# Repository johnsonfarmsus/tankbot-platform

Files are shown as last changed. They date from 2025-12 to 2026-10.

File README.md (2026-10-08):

# TankBot

**A robot platform that scales with what you plug into it, and to whatever size you build it.**

Start with an ESP32, a motor driver and a chassis, and you have a robot you can drive from a browser.
Add a bumper and distance sensors, and it protects itself. Put a phone on it, and the phone becomes its
brain. Add a lidar, and it maps your house, keeps the map straight, drives itself to wherever you tap,
and explores rooms it hasn't seen yet, all on hardware you probably already own.

<table align="center"><tr>
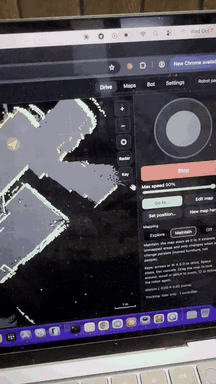
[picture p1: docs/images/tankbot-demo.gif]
TankBot in action
<td align="center"><br><em>In action</em></td>
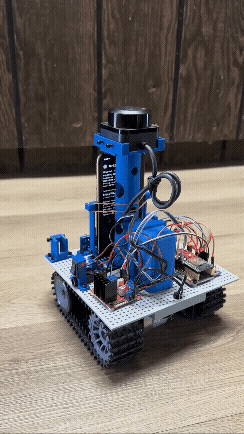
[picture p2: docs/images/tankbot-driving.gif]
TankBot driving
<td align="center"><br><em>Driving</em></td>
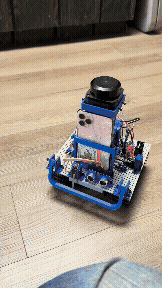
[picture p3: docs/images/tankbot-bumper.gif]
The bumper reflex
<td align="center"><br><em>Bumper reflex</em></td>
</tr></table>

TankBot grew out of the original [TankBot ESP32](https://github.com/johnsonfarmsus/tank-bot-esp32), a
web-controlled tracked robot. This project turns it into a platform: the same software for any robot
you build on it.

## One platform, any robot, any size

Nothing in TankBot is written for one particular robot. Each robot is **described** in its *bot
profile*: how big it is, how it drives, and where every sensor sits and how high. Everything else works
from that description:

- **Planning and safety use the robot's real footprint.** Routes keep its body (plus the clearance you
  choose) away from walls; the "is it clear ahead?" check uses its actual front edge and width.
- **Sensors are placed, not hard-coded.** Any number of bumpers, ultrasonic and ToF sensors, in any
  direction, each with a role (obstacle, cliff, bump). The robot reacts in the direction each one faces.
  The lidar and camera positions turn their readings into the robot's frame.
- **Driving adapts to the machine:** minimum and cruise power, steering trim, stop and pass distances,
  turn behaviour.
- **Maps are in metres, not robot sizes:** 5 cm cells, room for a whole house (up to 40 m across).
- **Brains are interchangeable.** Any iPhone with ARKit can be the brain (tested: SE 2nd gen, 11 Pro,
  12 Pro; a LiDAR iPhone adds a depth camera), mounted on the robot or held in hand. The robot itself keeps its settings, sensors and a
  compact copy of its map, so a new phone picks everything up when it connects.

| | TankBot (today) | Wheelchair base (next) | Yours |
|---|---|---|---|
| Size | 18.5 x 17 cm platform | wheelchair-sized | describe it in the profile |
| Drive | tank tracks | two powered wheels + casters | tank or two-wheel (mecanum planned) |
| Brain | iPhone on a 3D-printed tower | a phone on the chassis | any ARKit iPhone, mounted or in hand |
| Sensors | lidar, front bumper, ultrasonic | lidar, bumpers, rangers all round | whatever you attach, wherever it sits |
| Software changes | | none planned: a new profile | none: a new profile |

The **capability tiers** below grow with the hardware: every part you add unlocks more, and the app
shows what the next part would unlock.

## Build one

### Parts list

**Electronics**

| Part | Qty | Used for | Notes |
|---|---|---|---|
| **ESP32 DevKit**, 38-pin (CP2102, USB-C) | 1 | the robot's controller | |
| **ESP32 38-pin expansion board** ("ESP32S 38P V4" style) | 1 | mounts the ESP32; power and wiring | DC input 6.5-16 V, onboard 5 V and 3.3 V, an S/V/G header for every pin (a jumper sets V to 3.3 V or 5 V). Also powers the lidar (5 V) |
| **L298N** H-bridge motor driver | 1 | drives both tracks | remove the ENA / ENB jumpers so the ESP32 controls speed |
| **TP101 tracked chassis** with 2x **33GB-520-18.7F** DC motors | 1 | the robot base | |
| **12 V Li-ion battery pack**, 3S (11.1 V, 9-12.6 V), ~5600 mAh, 5 A | 1 | power | we use a Mspalocell XZ01 kit: it comes with a 12.6 V 1 A charger, bare leads, a DC barrel connector, lever connectors and barrel-to-screw-terminal adapters, which cover all the power wiring |
| **Mini rocker switch**, SPST on/off, 2-pin pre-wired (KCD1-101 type) | 1 | main power switch | fits the printed charger clamp with switch; sold in packs (e.g. AKVIBG 10-pack) |
| **Dupont jumper wires** (female-female and male-female) | a pack | every signal and sensor connection | the expansion board's S/V/G headers take standard Dupont plugs |

**Sensors**

| Part | Qty | Used for | Notes |
|---|---|---|---|
| **Slamtec RPLidar C1** | 1 | mapping, position, navigation | on the printed lidar tower; 5 V from the expansion board |
| **HC-SR04P** ultrasonic (wide-voltage 3-5.5 V) | 1 | low obstacles ahead | powered from 3.3 V so its echo is safe for the ESP32 |
| **V-153-1C25** micro switch | 1 | front bumper | behind the printed bumper bar |
| *Optional:* **TOFSense-F2 Mini** ToF sensor | 1 | cliff (drop-off) sensor, aimed at the floor | JST GH 1.25 mm connector |

**Brain**

| Part | Qty | Used for | Notes |
|---|---|---|---|
| **An iPhone with ARKit** | 1 | the brain | tested: SE (2nd gen), 11 Pro, 12 Pro; a LiDAR iPhone adds the depth camera. It runs on its own battery |

**Hardware**

| Part | Qty | Used for | Notes |
|---|---|---|---|
| **M3 x 6 mm socket head cap screws** | a pack (a full build uses under 50) | everything | the only fastener: every printed part, board and module mounts with these |
| [**3D-printed parts**](https://www.printables.com/model/1869360-tankbot) | 1 set | tower, mounts, clamps, bumper | on Printables |

**Recommended upgrade:** a **12 V to 5 V buck converter** (2 A or more) for the 5 V rail. The expansion
board's onboard 5 V is a small linear regulator that runs hot feeding the lidar and the ESP32 from a 12 V
battery; a buck converter runs cool. It is also what you would need to charge the phone from the robot,
though the battery above is better kept for driving.

### Build steps

1. **Print the parts** from [Printables](https://www.printables.com/model/1869360-tankbot) (base plate,
   lidar tower and base, phone base and clamp, bumper and switch mount, two-part ultrasonic mount, battery
   and charger clamps, a 2-wire connector, wire management, spacers). If Printables is ever unavailable,
   a backup zip of the model files is in [`hardware/`](hardware).
2. **Assemble** the chassis and mount the printed parts, the boards and the sensors, all with M3 x 6 mm
   screws. The printed spacers sit between each board and the base to lift it off.
3. **Wire it** following [docs/wiring.md](docs/wiring.md): battery through the rocker switch to the
   expansion board and the L298N, then the motors, lidar, ultrasonic and bumper with Dupont wires.
4. **Flash and set it up** following *Setting up a robot* below.

<p align="center">
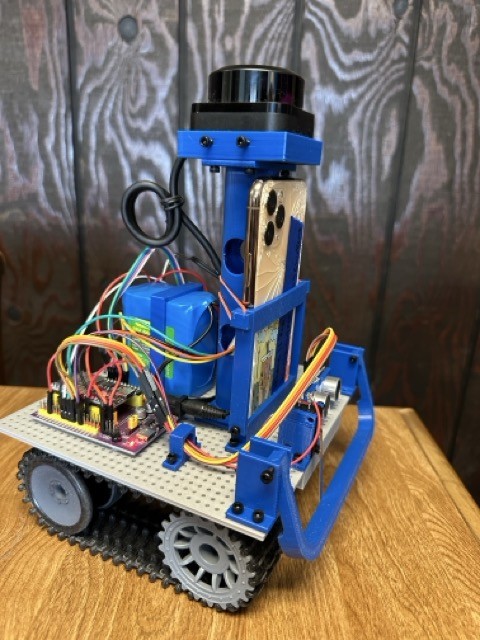
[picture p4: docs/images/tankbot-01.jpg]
TankBot photo 1

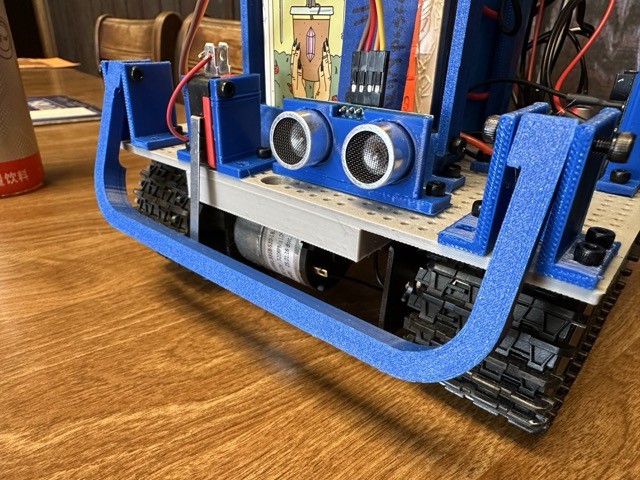
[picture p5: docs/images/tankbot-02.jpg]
TankBot photo 2

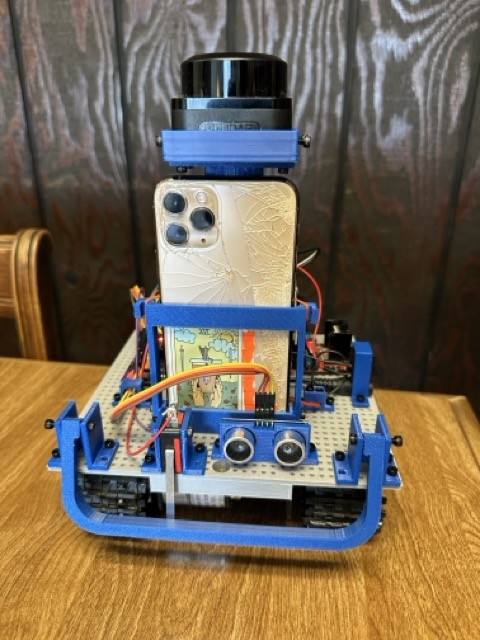
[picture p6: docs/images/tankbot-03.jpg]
TankBot photo 3

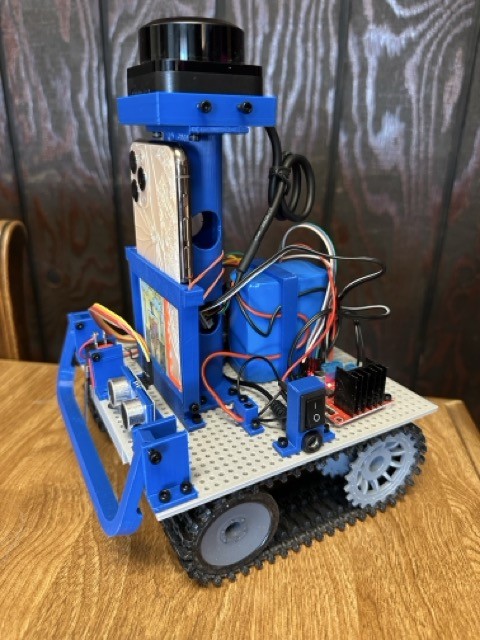
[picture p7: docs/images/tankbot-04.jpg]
TankBot photo 4

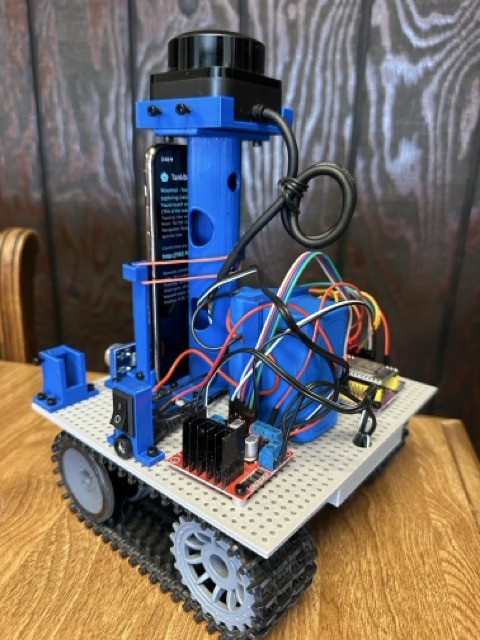
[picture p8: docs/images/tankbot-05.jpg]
TankBot photo 5

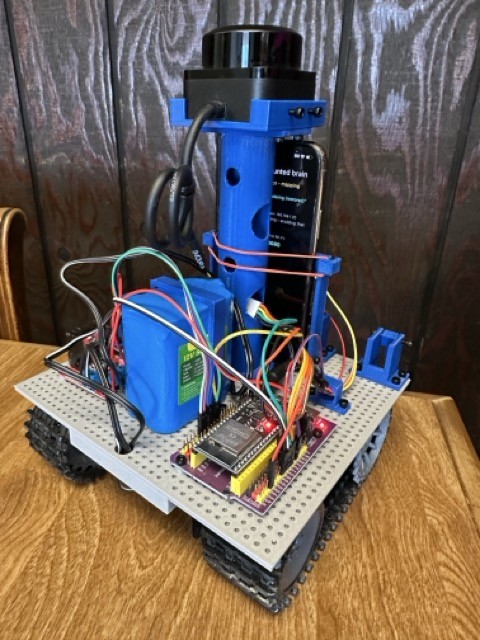
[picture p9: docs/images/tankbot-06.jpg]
TankBot photo 6

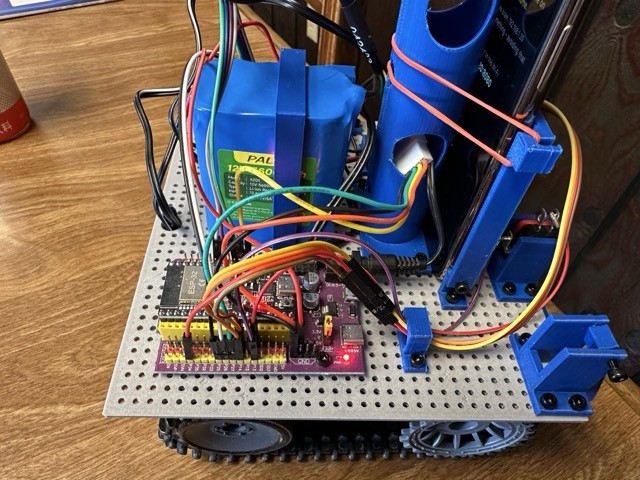
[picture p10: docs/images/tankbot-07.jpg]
TankBot photo 7

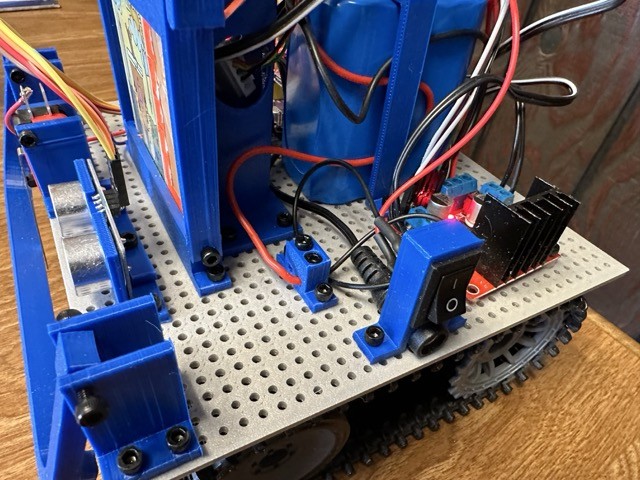
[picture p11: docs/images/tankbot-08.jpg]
TankBot photo 8

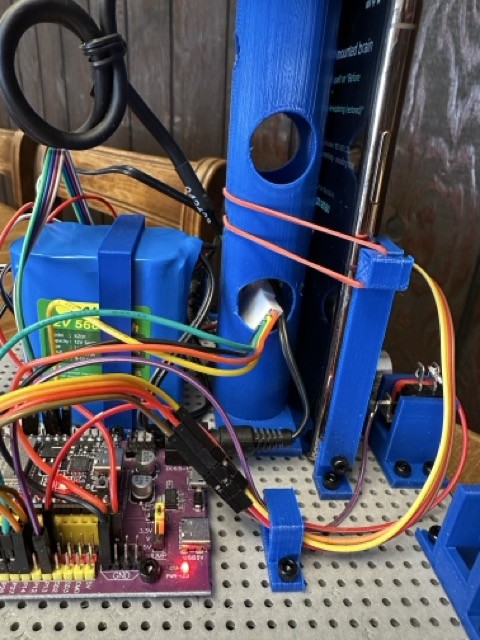
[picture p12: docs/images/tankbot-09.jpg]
TankBot photo 9

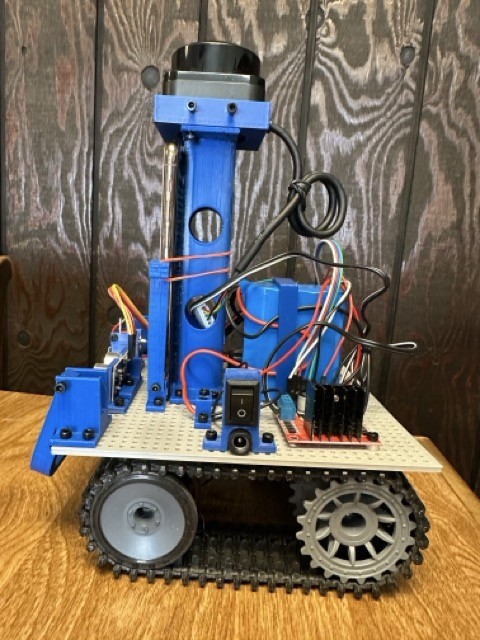
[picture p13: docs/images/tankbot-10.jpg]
TankBot photo 10

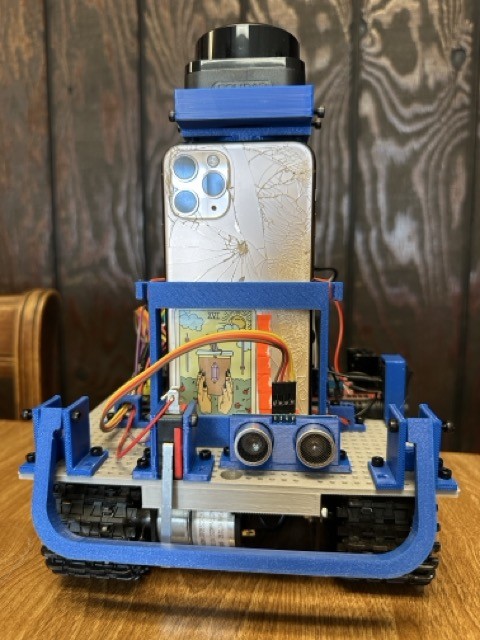
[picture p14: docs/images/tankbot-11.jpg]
TankBot photo 11

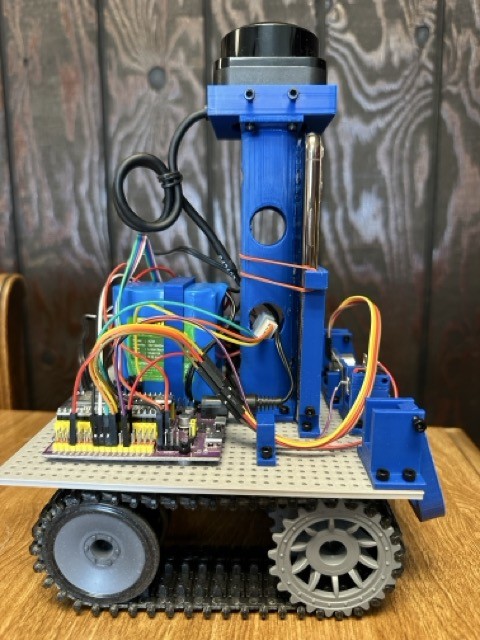
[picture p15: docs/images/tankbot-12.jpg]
TankBot photo 12

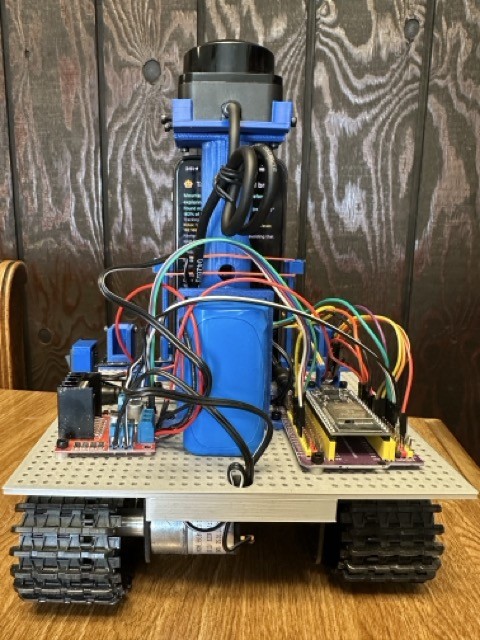
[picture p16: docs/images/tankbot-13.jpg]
TankBot photo 13

</p>

TankBot grew out of the original [TankBot ESP32](https://github.com/johnsonfarmsus/tank-bot-esp32)
(a browser-driven tracked robot, with its own [Printables parts](https://www.printables.com/model/1516204-tank-bot-esp32)).
Building something bigger? The same steps apply: a motor driver that suits your motors, the sensors you
want where you want them, and a profile that describes it.

## How it fits together

```
 Robot (ESP32)                         Brain (phone/tablet running the app)         Controllers
 motors + watchdog                 --->  tracking: camera + lidar scan matching  <---  web browser
 reflexes: bumper / cliff / range        map: keyframes, loop closing, edits           (any laptop)
 lidar bridge                            guardian: is forward clear, and why?    <---  the app in
 sensor feed + capability announce       navigator: plan a route, drive it             Controller role
 own web page (drive + setup)            control server (web pages + live data)
```

Every part reads the robot's geometry from a **bot profile** (size, drive type, where each sensor
sits). Nothing about a specific robot is hard-coded.

## Capability tiers

| Tier | Hardware | You get |
|---|---|---|
| Drive | ESP32 + motor driver + chassis | manual driving from the ESP32's own web page |
| Reflexes | + bumpers, ToF, ultrasonic | bump stop and back-off, cliff stop, close-obstacle stop, on the ESP32 itself |
| Brain | + a phone or tablet running the app | full controller, position tracking (mounted), the robot's status face |
| Mapping | + RPLidar | maps, remembering places, relocalisation, tap-to-go |
| 3D awareness | + a phone with a depth camera (LiDAR iPhone) | low obstacles and drop-offs the lidar can't see |

The controller's Settings page shows the current tier and what would unlock the next.

## Repository layout

| Folder | Contents |
|---|---|
| `firmware/tankbot/` | ESP32 firmware v3: sensor table, directional reflexes, lidar bridge, sensor feed, web page, OTA |
| `firmware/motion/` | the original TankBot firmware, kept for reference |
| `app/tankbot_brain/` | the **TankBot** app (Flutter): Mounted brain / Brain in hand / Controller roles |
| `docs/` | [user guide](docs/user-guide.md), [wiring](docs/wiring.md), [protocol](docs/protocol.md), [bot profile](docs/bot-profile.md), [app architecture](docs/app-architecture.md), [diagnostics](docs/diagnostics.md), [roadmap](docs/ROADMAP.md), [changelog](CHANGELOG.md) |
| `tools/` | desktop helpers: log analysis, brain commands, controller checks ([tools/README](tools/README.md)) |
| `hardware/` | a backup zip of the 3D-printed parts (STL + Fusion 360); get the parts from [Printables](https://www.printables.com/model/1869360-tankbot) |

## Setting up a robot

1. **Wire it** following [docs/wiring.md](docs/wiring.md). Start with the motor driver; add sensors
   any time.
2. **Flash the firmware.** Copy `firmware/tankbot/src/secrets.example.h` to `secrets.h`, enter your
   2.4 GHz Wi-Fi, an OTA password and a hotspot password, then `cd firmware/tankbot && pio run -t upload` over USB once.
   From then on `pio run -e ota -t upload` updates it over Wi-Fi.
3. **Drive it.** Open `http://tankbot.local/` on any device on your Wi-Fi (buttons, joystick, or the
   arrow keys / W A S D on a computer) (away from home the robot
   broadcasts its own `TankBot` network instead). Speed levels and steering trim live here too.
4. **Tell it what's attached.** Once a brain is running (below), the **Bot** page describes the whole
   robot: its size and drive type, and each sensor's role, facing and position; its **Wiring** view
   sets and checks the pins (defaults match docs/wiring.md) with test buttons. Save sends it to the
   robot, which keeps it. `http://tankbot.local/setup` covers Wi-Fi, name and pins. A ToF aimed
   at the floor? Press Calibrate on its card once.

## Adding a brain

1. Install the **TankBot** app on a phone (iOS today; Android when ARCore support lands). Each time it
   opens it asks what the device is doing:
   - **Mounted brain**: the phone rides on the robot; camera tracking, mount detection, status face.
   - **Brain in hand**: same brain off the robot, tracking with the lidar alone.
   - **Controller**: a remote for a brain on the network.
2. Open **`http://tankbot.local/brain`** in any browser on the same Wi-Fi: the robot sends you to
   wherever the brain is (bookmark it). The robot's own page (`tankbot.local`) also shows an
   "Open full controls" button whenever a brain is running. The app's Controller role works too.
3. Controller pages: **Drive** (map you can drag, zoom and pinch, follow-the-robot, a colour key,
   joystick, arrow keys, radar view, Go to... anywhere on the map, status cards with actions), **Maps**
   (save, load, edit, no-go lines, map quality), **Bot** (the profile: platform size, sensor
   positions and heights), **Settings** (trim, power levels, obstacle stop and pass distances,
   what the robot and the phone can do).

### Which phone, and mounting it

Any iPhone with ARKit works as a brain. A LiDAR iPhone (12 Pro and later Pros) adds the depth camera
(low obstacles, drop-offs); without one (e.g. iPhone SE) the brain runs one tier down and falls back to
lidar-only tracking when the camera drifts (dim rooms, plain walls).

Mount it upright or on its side (set "Brain phone mounted" on the Bot page; the screen locks to it)
with the back camera facing forward. Enter the camera's position and height in the Bot page.
In Robot mode the brain waits until the phone has sat still in its cradle for 3 s before mapping, so
handling the phone never smears a map. If the phone gets knocked, mapping pauses until it settles.

## Mapping and driving

See the [user guide](docs/user-guide.md) for every page, button and map symbol.

- **Mapping modes:** Explore (build the map deliberately), Maintain (default: grows into new areas and
  only changes for persistent changes), Off. Bumps and drop-offs are temporary unless they recur.
- **Go to...:** click anywhere on the map. It plans around walls, no-go lines and live obstacles,
  backs away and re-plans when blocked or stalled, and stands still when unsure where it is.
- **Explore on its own** (Explore mode): drives to unexplored edges room by room and comes home.
- **Set position** when it's lost; **restore points** undo bad mapping (Maps page).
- Map straightening keeps long maps square (wall alignment, loop closing, good GPS outdoors).
- Safety is layered: ESP32 watchdog -> on-board reflexes -> the brain's guardian -> the controller's
  watchdog. Autonomous driving always runs its own obstacle checks.
- Trip, position-event and sensor logs record what happened; see [diagnostics](docs/diagnostics.md).

## Developing

- Firmware: PlatformIO. `pio run -e esp32dev` builds; `pio run -e ota -t upload` deploys over Wi-Fi.
- App: Flutter 3.32+. `flutter test` runs the mapping, matching, planning, guardian, pose graph and
  exploration tests (must pass before every install);
  `flutter build ios` / Xcode for the phone.
- The wire protocols are in [docs/protocol.md](docs/protocol.md); `tools/lidar_client.py` is a
  minimal reference client.

## Security and privacy

For a trusted home network: the robot's and brain's controls have no login, so never expose them to
the internet. Everything the app collects stays on your devices. Details, and the pre-commit secret
check (`git config core.hooksPath .githooks`), in [SECURITY.md](SECURITY.md).

## License

GNU AGPL 3.0 (inherited from tank-bot-esp32).

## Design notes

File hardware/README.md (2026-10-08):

# TankBot 3D-printed parts

**Get the parts from Printables:** [TankBot on Printables](https://www.printables.com/model/1869360-tankbot).
That is the home of the TankBot parts: print settings, photos, updated parts and new additions all land
there first. Downloading, liking and posting your makes there also supports the project.

[`tankbot-modelfiles.zip`](tankbot-modelfiles.zip) here is a ready-to-go backup pack of the parts as
of this release, in case Printables is ever unavailable: `.stl` files to print and `.f3d` Fusion 360
sources. It is not updated as often as Printables.

**In the pack:** base plate, lidar tower and lidar base, phone base and phone clamp, bumper and bumper
switch mount, two-part ultrasonic mount, battery clamp, charger clamp (with and without a switch),
2-wire connector, wire management, and spacers (they sit between an electronics board and the base,
with the screw passing through both, to lift the board off).

**One screw for everything:** every printed part, board and module mounts with **M3 x 6 mm socket head
cap screws**.

The base robot (chassis, motors, original mounting parts) comes from the original
[TankBot ESP32](https://github.com/johnsonfarmsus/tank-bot-esp32) project and its
[Printables parts](https://www.printables.com/model/1516204-tank-bot-esp32).

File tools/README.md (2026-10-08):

# Tools

Desktop helpers for developing and diagnosing the robot. Python 3; `analyze_sensor_log.py` and
`nopath_check.py` need numpy / matplotlib / Pillow (`~/tankbot-work/venv`). See `../docs/diagnostics.md`
for how to pull logs off the brain phone.

| Tool | What it does |
|---|---|
| `analyze_nav.py nav_*.csv` | breaks down a Go To / exploration trip: time by decision, motor bursts, interruptions, re-plans, turn reversals, timing and watchdog health |
| `analyze_sensor_log.py log_*.csv` | evaluates GPS and compass against the tracked path; writes a plot next to the log |
| `brain_send.py '{"type":"..."}'` | sends one controller message to the brain (default 192.168.1.99, or `BRAIN=host`) and prints pose, flash and exploration state |
| `nopath_check.py` | rebuilds what the planner sees from the live map and shows what boxes the robot in |
| `cdp_check.py URL [seconds] [js]` | loads the controller in headless Chrome, reports state and errors, optionally evaluates JS |
| `lidar_client.py` | minimal lidar client with a live plot (reference implementation of the protocol) |
| `wiring_check_test.js CONTROLLER_HTML` | runs the controller's wiring checker against 10 known scenarios (node) |
| `check_secrets.py` | the pre-commit secret check (enable with `git config core.hooksPath .githooks`) |
| `make_icon.py [artwork] [fill]` | regenerates the app icon at every iOS and Android size from one image |

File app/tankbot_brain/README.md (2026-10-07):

# TankBot app

The TankBot app (Flutter, iOS today): one app, three roles chosen at launch.

- **Mounted brain**: the phone rides on the robot (camera tracking, mapping, navigation, control server).
- **Brain in hand**: the same brain off the robot, tracking with the lidar alone.
- **Controller**: a remote for a brain on the network.

See the [project README](../../README.md), the [user guide](../../docs/user-guide.md) and the
[app architecture](../../docs/app-architecture.md). The Dart package is still named `tankbot_brain`
internally (folder, imports, bundle id `com.johnsonfarms.tankbotBrain`) so installed phones keep their data.

`flutter test` must pass before every install.

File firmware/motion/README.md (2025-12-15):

# TankBot - ESP32 Web-Controlled Tracked Robot

A web-controlled tank robot built with ESP32 and L298N motor driver, featuring a responsive web interface with speed control.

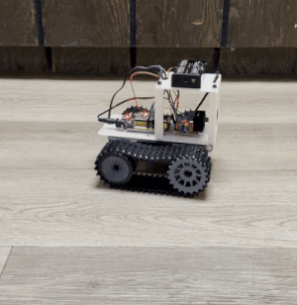
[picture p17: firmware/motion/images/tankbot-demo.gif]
TankBot in Action


## Hardware Components

- **Microcontroller**: ESP32 DevKit (38-pin, CP2102, USB-C)
- **Motor Driver**: L298N H-Bridge
- **Motors**: 2x 33GB-520-18.7F DC motors (included with chassis)
- **Chassis**: TP101 Tank-style chassis ([widely available](https://www.google.com/search?client=safari&rls=en&q=TP101+chassis&ie=UTF-8&oe=UTF-8))
- **Power**: 2x 18650 lithium batteries (7.4V nominal) (holder included with chassis)
- **Fasteners**: 12x M3x6 screws

### 3D Printed Parts

Custom mounting brackets and accessories are available on Printables: [TankBot ESP32 on Printables](https://www.printables.com/model/1516204-tank-bot-esp32)

## Wiring Diagram

### ESP32 to L298N Connections

| ESP32 Pin | L298N Pin | Function |
|---|---|---|
| P16 | IN1 | Left motor direction |
| P17 | IN2 | Left motor direction |
| P18 | IN3 | Right motor direction |
| P19 | IN4 | Right motor direction |
| P25 | ENA | Left motor speed (PWM) |
| P26 | ENB | Right motor speed (PWM) |
| GND | GND | Common ground |

### L298N Setup

1. **Remove the jumpers** from ENA and ENB pins on the L298N
2. Connect ENA to P25 and ENB to P26 as shown above
3. Connect your battery power to the L298N power input
4. Connect motors to OUT1/OUT2 (left) and OUT3/OUT4 (right)

### Power Connections

The TP101 chassis includes a dual 18650 battery holder with a power switch. Wire the power as follows:

1. **Battery to L298N**:
   - Connect battery holder red wire (+) to L298N 12V input
   - Connect battery holder black wire (-) to L298N GND

2. **L298N to ESP32**:
   - Connect ESP32 5V pin to L298N 5V input (this powers the L298N's logic circuitry)
   - Connect L298N GND to ESP32 GND (common ground)
   - The ESP32 is powered via USB during programming, or via a barrel plug connector tapped from the battery wires during operation

3. **Important Notes**:
   - The dual 18650 setup provides 7.4V nominal (8.4V fully charged)
   - The batteries power the L298N's motor outputs via the 12V input
   - The ESP32's 5V pin powers the L298N's logic circuitry
   - Always connect common ground between all components
   - During operation, power the ESP32 with a barrel plug connector from the battery wires

## Software Setup

### Prerequisites

- [PlatformIO](https://platformio.org/) installed in VSCode or via CLI
- USB cable to connect ESP32 to computer

### Installation

1. Open this project in PlatformIO:
   ```bash
   cd TankBot
   ```

2. Build the project:
   ```bash
   pio run
   ```

3. Upload to ESP32:
   ```bash
   pio run --target upload
   ```

4. Monitor serial output (optional):
   ```bash
   pio device monitor
   ```

### First Time Upload

If you encounter upload issues:
- Make sure the ESP32 is connected via USB
- Press and hold the BOOT button on ESP32 during upload if needed
- Check that the correct port is detected

## How to Use

1. **Power on the robot** - Connect battery and power up the ESP32

2. **Connect to WiFi**:
   - SSID: `TankBot`
   - Password: `tankbot2025`

3. **Open web interface**:
   - Open browser and go to: `http://192.168.4.1`

4. **Control the robot**:
   - **Button Mode** (default): Arrow buttons for Forward, Backward, Left, Right
     - Press and hold buttons to move, release to stop
     - Red STOP button for emergency stop
   - **Joystick Mode**: Click 🕹 icon (top-left) to toggle joystick control
     - Drag joystick to control direction and turning simultaneously
     - Forward/backward movement + left/right steering
     - Release joystick to stop
   - Adjust speed slider for 3 speed levels: Slow, Medium, Fast (works in both modes)

5. **Calibrate steering** (if robot drifts to one side):
   - Click the ⚙️ (gear) icon in the top-right corner to open Settings
   - Drive forward and observe which direction it drifts
   - Adjust the "Steering Trim" slider in the settings popup:
     - If drifting LEFT: Move slider to the RIGHT
     - If drifting RIGHT: Move slider to the LEFT
   - Fine-tune until robot drives straight
   - Close the settings popup (trim is automatically saved)

## Features

- **WiFi Access Point**: Robot creates its own WiFi network
- **Captive Portal**: Auto-popup control interface when connecting
- **Responsive Web UI**: Works on phones, tablets, and computers
- **Dual Control Modes**: Toggle between button controls and joystick
  - Button mode: Discrete directional controls (Forward, Backward, Left, Right)
  - Joystick mode: Analog control with simultaneous forward/back and turning
- **Speed Control**: 3 speed levels (Slow: 160, Medium: 220, Fast: 255)
- **Steering Trim**: Compensate for uneven track tension (-20 to +20 adjustment)
  - Trim value is saved to flash memory and persists between power cycles
  - Automatically loaded on startup
  - Works in both button and joystick modes
- **Real-time Feedback**: Status updates on web interface
- **Touch Support**: Works with touch screens for mobile control
- **mDNS Support**: Access via http://tank.local

## Control Mechanics

- **Forward/Backward**: Both motors run in same direction
- **Left**: Left motor backward, right motor forward (spin in place)
- **Right**: Left motor forward, right motor backward (spin in place)
- **Speed**: PWM control (0-255) on ENA/ENB pins

## Troubleshooting

### Robot doesn't move
- Check battery is charged and connected
- Verify all wiring connections
- Check that jumpers are removed from ENA/ENB
- Use serial monitor to see debug output

### Can't connect to WiFi
- ESP32 might still be booting (wait 10-15 seconds)
- Check password is correct: `tankbot2025`
- Move closer to the robot
- Restart ESP32

### Motors run at full speed regardless of setting
- Ensure jumpers are removed from ENA and ENB
- Verify P25 and P26 are connected to ENA and ENB

### Web page doesn't load
- Verify you're connected to TankBot WiFi
- Try `http://192.168.4.1` directly
- Clear browser cache
- Check serial monitor for ESP32 IP address

## Customization

### Change WiFi Credentials

Edit in [src/main.cpp](src/main.cpp):
```cpp
const char* ssid = "TankBot";
const char* password = "tankbot2025";
```

### Adjust Speed Levels

Edit in [src/main.cpp](src/main.cpp):
```cpp
#define SPEED_SLOW 100    // Range: 0-255
#define SPEED_MEDIUM 180  // Range: 0-255
#define SPEED_FAST 255    // Range: 0-255
```

### Change Pin Assignments

Edit pin definitions in [src/main.cpp](src/main.cpp):
```cpp
#define IN1 16
#define IN2 17
#define IN3 18
#define IN4 19
#define ENA 25
#define ENB 26
```

## Serial Monitor Output

When connected via serial, you'll see:
```
=== TankBot Starting ===
Motors initialized
Setting up Access Point: TankBot
AP IP address: 192.168.4.1
HTTP server started

=== TankBot Ready! ===
Connect to WiFi: TankBot
Password: tankbot2025
Then visit: http://192.168.4.1
========================
```

## License
GNU AGPL 3.0 
Open source - feel free to modify and improve!

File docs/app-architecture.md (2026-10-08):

# App architecture

Last updated: 2026-10-06. One Flutter app (`app/tankbot_brain`), three roles. The controller UI is a
web page served by the brain, so any browser (and the app's Controller role) uses the same pages.

## Roles

| Role | Runs on | What it does |
|---|---|---|
| **Mounted brain** | the phone on the robot | camera tracking (ARKit) + lidar, mount detection, orientation lock, keep-awake status face, hosts the control server |
| **Brain in hand** | any phone/tablet on the network | the same brain tracking with the lidar alone |
| **Controller** | any phone/tablet | a WebView of a brain's control pages |

Leaving the foreground stops the robot. Any self-driving needs a controller connected.

## Data flow

```
 ESP32: motion (UDP 5602), lidar bridge (5601), sensor feed + reflexes (5603), web page + /setup
   |                                   ^
   v                                   | drive commands at 20 Hz (robot watchdog: 300 ms)
 Brain (main.dart)
   Robot link      find tankbot.local, fall back to the last address, reconnect after silence
   Tracking        camera pose (pose_client: glitch filter) corrected by lidar scan matching,
                   or lidar alone; trust gating; drift / spin / wide-search handling
   Mapping         mode: explore | maintain | off; keyframes -> occupancy grid; edits; pose graph
   Guardian        one forward-clear decision from body geometry, lidar, reflexes, rangers, depth
   Navigator       planner + follower; recovery, stall detection, settle; exploration on top
   Control server  web page + WebSocket (brain_server.dart, assets/controller.html)
   Logs            trip recorder, position events, sensor log
```

## Modules (`lib/`)

| File | Role |
|---|---|
| `main.dart` | the brain: link, tracking, mapping modes, guardian use, navigation, exploration, recovery, telemetry, logs |
| `brain_server.dart` | HTTP + WebSocket server; serves `assets/controller.html` |
| `bot_profile.dart` | profile model, hardware-table merge, settings that travel with the robot |
| `lidar_client.dart`, `motion_client.dart`, `sensor_client.dart` | UDP links to the ESP32 |
| `pose_client.dart` | ARKit pose + depth stream; smooths over impossible camera leaps |
| `scan_matcher.dart` | likelihood-field matching (local, coarse-fine, global) |
| `occupancy_grid.dart` | log-odds grid, rendering, erase/mark, likelihood field |
| `map_store.dart` | per-robot maps, keyframes (TKF1), edits, graph, restore points |
| `pose_graph.dart` | Levenberg-Marquardt pose graph with a skyline solver; wall direction |
| `loop_closer.dart` | loop detection against first visits |
| `frontier.dart` | exploration targets: gap closing, rooms, reachability, stats |
| `planner.dart` | A* on the grid inflated by the body radius + pass distance |
| `guardian.dart` | forward-clear decision from the profile's body geometry |
| `depth_obstacles.dart` | depth camera -> low obstacles and drop-offs (floor-missing test) |
| `sensor_log.dart` | GPS / compass / pose recorder |
| `app_settings.dart`, `role_screens.dart` | role, last robot and address, role UI |

## Tracking

Each lidar scan is matched against the map around the predicted pose (camera, or the last lidar pose).

- **Trust:** a scan is drawn into the map only if it agrees with the parts of the map it lands on;
  in new territory (little known) the camera carries the pose.
- **Doubt:** after 2 s of untrusted scans, self-driving stands still; after 15-17 s it stops (exploring
  also rolls back the keyframes from just before).
- **Drift:** repeated misses widen the window (35 cm); still lost, a Set-position-style wide search
  (60 cm, 20 deg) runs every 1.5 s. A confident match more than 10 cm from the camera snaps to the
  lidar, only when at least half the scan lies on known map.
- **Camera health:** leaps beyond physical limits between frames are smoothed over in the pose stream;
  a camera that reports motion while the motors are idle is distrusted for 30 s (lidar only). Settings
  can force lidar only.
- **Spins:** scans taken while turning faster than 60 deg/s are not matched or drawn (they are smeared).
- **Lidar only** (by choice, or while the camera is benched): turning between scans comes from the
  phone's raw gyro (CoreMotion, independent of the camera, direction checked against the lidar), and
  the robot carries on at its recent speed through missed scans instead of freezing.
- **A broken camera is benched:** 3+ impossible jumps within 5 s, or motion reported while the motors
  are idle, switch to lidar only for a while and restart ARKit; autofocus is locked; ARKit's
  tracking-state reason and visual-feature count are logged.
- **Set position** fine-tunes within 50 cm / 25 deg, and searches every heading around the pressed
  spot when the dragged direction doesn't fit.
- **Relocalisation:** quick checks (last pose, home spot), then a whole-map search; while self-driving
  only near the current pose (never a jump across the map).

## Wiring

The robot's hardware table holds each sensor's pins (a default slot or custom pins) and the motor
driver and lidar pins; the brain carries them in the profile. The controller's Bot > Wiring view edits
them against a pin rule-book (usable, input-only, boot, flash and USB-serial pins) and blocks saving
on conflicts; the firmware runs the same checks at startup and doesn't start a sensor whose wiring
can't work (reporting why). `tools/wiring_check_test.js` runs the controller's checker against known
scenarios.

## Mapping

- **Modes:** Explore (every trusted scan, keyframes, loop closing, straightening), Maintain (default;
  extends into unmapped ground; elsewhere a spot changes only after 3 separate passes over 10+ min
  that clearly disagree with the map), Off (nothing written). Self-driving caps Explore to Maintain,
  except autonomous exploration.
- **Pose graph:** driving links between consecutive keyframes, loop links, wall-alignment heading priors
  (houses are square), GPS fixes better than the threshold once they span 15 m. Runs every 40 keyframes
  and on loops; redraws only if something moved > 3 cm / 0.6 deg.
- **Marks:** bumps, stalls and drop-offs are temporary (15 min) unless they recur 10+ min later.
- **Restore points:** before switching to Explore and before exploring; the newest 6 are kept.

## Navigation

Planner (A*, live obstacles) -> follower: turn on the spot only beyond 30 deg, in pulses, ending at
12 deg or on overshoot, then a 350 ms settle; steering while driving within the cruise - minimum power
margin. Re-plans every 8 s or after 3 consecutive sightings of something on the route. Blocked > 1.2 s
or stalled ~2 s: mark the spot, back up 25 cm if the rear is clear, settle, re-plan; give up after 4.

## Exploration

`frontier.dart` picks the next target: open floor next to unexplored space at least 30 cm from walls
(gaps under ~60 cm count as closed), leading to real unexplored space, reachable by the body, in the
robot's own room first (doorways under ~1 m split rooms). Pauses 1 s every 40 cm in new territory.
"Nothing left" must repeat 3 times before it drives home.

## Storage (per robot)

```
Documents/
  app_role.json                         role, brainUrl, lastRobot, lastRobotIp
  robots/<name>/bot_profile.json
  robots/<name>/maps/last.json
  robots/<name>/maps/<id>/meta.json, keyframes.bin, edits.json, graph.json
  robots/<name>/maps/<id>/restore/<time>/...   restore points
  logs/nav_*.csv  logs/events_*.csv  logs/log_*.csv
```

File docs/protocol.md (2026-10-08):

# TankBot Platform protocol

Last updated: 2026-10-07 (firmware v3.1).

All messages are UDP. Multi-byte numbers are little-endian. Devices advertise themselves with mDNS/Bonjour so clients never need hardcoded IP addresses.

## Lidar bridge

- mDNS host: `tankbot.local` (single host for web page, lidar and motion)
- Bonjour service: `_tanklidar._udp`, port **5601**

### Subscribing

The client sends the 5-byte ASCII message `TLSUB` to port 5601. The bridge streams to that client's IP and source port. The client must resend `TLSUB` at least every **5 s** (1 s recommended); otherwise the subscription expires. Up to 3 subscribers at once.

### Scan packet `TLS1`

One full rotation is split into chunks of up to 250 points.

| Offset | Type | Field |
|---|---|---|
| 0 | char[4] | `TLS1` |
| 4 | u32 | rotation number |
| 8 | u32 | bridge `millis()` at rotation start |
| 12 | u8 | chunk index (0-based) |
| 13 | u8 | chunk count |
| 14 | u16 | n = points in this chunk |
| 16 | n x 5 bytes | points |

Each point: `u16 angle_q6` (degrees = value / 64, clockwise from the lidar's front), `u16 dist_q2` (millimetres = value / 4), `u8 quality`. Only valid (non-zero distance) points are sent.

A rotation is complete when all `chunk count` chunks with the same rotation number have arrived. Drop incomplete rotations; the next one arrives 100 ms later.

### Clock sync `TLSYN` / `TLSY1`

The client sends `TLSYN` + `u32 seq` (9 bytes) to port 5601. The bridge replies immediately with `TLSY1` + `u32 seq` + `i64` bridge time in microseconds (17 bytes, same clock as `millis()`). The client keeps the reply with the smallest round-trip time and estimates `offset = bridge_ms - (sent + received) / 2`, which converts scan timestamps into its own clock. Send about once per second.

### Status packet `TLH1`

Sent once per second to each subscriber: `TLH1` followed by a JSON object, e.g.

```json
{"uptime_ms":46192,"revs":432,"hz":9.99,"pts":417,"sync_errs":0,"rssi":-49,"subs":1,"sent":193,"send_errs":0}
```

## Motion controller

- Bonjour service: `_tankmotion._udp`, port **5602**
- Web control page: `http://tankbot.local/` (original TankBot page, now with hold-to-drive keep-alive)

### Drive command `TMC1` (12 bytes)

| Offset | Type | Field |
|---|---|---|
| 0 | char[4] | `TMC1` |
| 4 | f32 | forward, -1..1 |
| 8 | f32 | turn, -1..1 (positive = same as pushing the web joystick to the right) |

Mixed on the robot exactly like the web joystick: `left = forward - turn`, `right = forward + turn`, normalised to at most 1, then scaled by the current speed level and trim.

**Watchdog:** commands must repeat at least every **300 ms** (send at 10-20 Hz). If they stop, the robot stops on its own. Web page commands have a 500 ms watchdog; the page resends every 150 ms while a control is held.

### Stop `TMS1` (4 bytes)

Immediate stop.

### Motion status `TMH1`

Sent every 250 ms to whoever sent a motion command in the last 3 s: `TMH1` + JSON, e.g.

```json
{"left":0.00,"right":0.00,"src":"none","wd_trips":0,"speed":220,"trim":18,"cmds":0}
```
`src` is `udp`, `web` or `none`; `wd_trips` counts watchdog stops since boot.

### Ping `TMP1` (4 bytes)

Keeps motion status (`TMH1`) flowing to the sender without moving the robot.

## Sensor feed and capabilities (firmware v3)

- UDP port **5603**.

### Subscribing `TSSUB`

The client sends `TSSUB` (resend every 2 s). The robot replies once with `TCAP1` + a JSON capability
announce (firmware version, name, drive type and the hardware table, the same as `GET /api/hardware`),
then streams `TSN1` + JSON at 20 Hz:

```json
{"t":905654,"sensors":[{"id":"us1","v":1113,"ok":true},{"id":"bump1","v":0,"ok":true}],
 "block":{"front":"ultrasonic"},"reflexEvents":0}
```

`block` lists the directions the robot's reflexes currently refuse to drive (front/back/left/right)
and why. Commands into a blocked direction are dropped on the robot itself.

### Brain announce `TBRN1:<port>`

A brain sends `TBRN1:8080` (ASCII) to port 5603 with each subscribe. The robot remembers the sender's
address for 10 s and uses it for `/api/brain` and the `/brain` redirect.

## Robot HTTP (port 80)

| Path | What |
|---|---|
| `/` | drive page: buttons, joystick, keyboard (arrows/WASD, Space stops), trim, speed, links |
| `/setup` | Wi-Fi, name, drive type, pins |
| `GET /api/hardware` | the sensor table (id, name, type, slot, pinA/pinB, role, enabled, yawDeg, floorTilt, stopMm, floorMm, backoffMs, placement) and `pins` (in1-in4, ena, enb, lidarRx, lidarTx). A sensor whose wiring failed the startup check carries `error` (and isn't started) |
| `POST /api/hardware` | replace the table and the pins (the robot restarts to apply) |
| `GET /api/info` | how to reach the robot: `name`, `host`, `ip`, `mode` (wifi / hotspot), `ssid`, `rssi`, `fw`, `brain` |
| `GET /api/test/motor?motor=a\|b&dir=1\|-1&ms=400` | run one motor briefly (wiring check; reflexes still apply). A = IN1/IN2/ENA, B = IN3/IN4/ENB |
| `GET /api/sensors` | live readings + directional blocks (same as `TSN1`) |
| `GET /tof/calibrate?id=X` | store the current reading of a floor-facing ToF as its floor distance |
| `GET /api/brain` | `{"url":"http://<brain>:8080/"}` if a brain announced itself in the last 10 s, else `{}` |
| `/brain` | 302 redirect to the brain; a help page if none is running |
| `GET` / `POST /api/settings` | robot-level brain settings (JSON with an `updated` time; the newer side wins). Stored in NVS, max ~3.8 KB |
| `GET /api/map/info` | `{id, name, updated, size, keyframes}` of the stored compact map, or `{}` |
| `GET /api/map` | the compact map file (`TCM1`, see below) |
| `POST /api/map/begin?size=N`, `POST /api/map/chunk` (body: base64, ~6 KB decoded), `POST /api/map/end` (body: info JSON) | chunked upload into LittleFS; the stored map is replaced only when all N bytes arrived. Send bodies as `text/plain` / JSON, not form-encoded |

### Compact map `TCM1`

`TCM1` + u32 header length (little-endian) + header JSON + zlib(cells). Cells: one byte per grid cell
over the map's bounding box, 0 unexplored, 1 open floor, 2 wall. Header: `id`, `name`, `created`,
`updated`, `res`, `x0`/`y0` (cell index relative to the grid centre), `w`, `h`, `lidarFwdM`,
`lidarLeftM`, `lastPose`, `nextEditId`, `edits`. Raw keyframes are not included.

## Controller WebSocket (brain, port 8080, path `/ws`)

JSON messages. The brain sends:

| type | when | content |
|---|---|---|
| `telem` | 5 Hz | pose, live scan, settings, stats, tracking, loc, nav, explore, quality, robot, guard, depth, rangers, marks, no-go lines, log, flash |
| `map` | when the map image changes | PNG (base64) + `left`, `top` (m) and `res` (m/pixel) |
| `maps` | on request / change | saved maps + the active map (with its restore points) |
| `bot` | on request / change | the bot profile |

Controllers send (`type` plus fields):

| type | fields | effect |
|---|---|---|
| `drive` | `f`, `t` (-1..1) | manual drive; cancels Go To and exploring |
| `stop` | | stop everything |
| `set` | any of `maxSpeed`, `obstacleStop`, `mappingMode`, `trackingMode`, `wallAlign`, `gpsMaxAccM`, `stopDistMm`, `passDistMm`, `depthStopMm`, `depthMinHeightMm`, `trim`, `minPower`, `cruisePower` | change settings (saved) |
| `nav.goto` / `nav.cancel` | `x`, `y` | Go to / stop |
| `explore.start` | `ackNoCliff` | start exploring (needs Explore mode; acknowledgment without a cliff sensor) |
| `explore.stop` / `explore.preview` | | stop / compute the next target without moving |
| `loc.set` | `x`, `y`, `h` | Set position (fine-tuned by the lidar) |
| `reloc` / `atHome` | | Try again (whole map) / I'm at home |
| `clearMap` | | new map here (saves the current one) |
| `maps.list`, `maps.save`, `maps.load`, `maps.delete` | `name` / `id` | map management |
| `map.restore` | `id` | put the map back to a restore point |
| `map.erase` | `x`, `y`, `r`, `stroke` | eraser (also removes marks under it) |
| `map.nogo` / `map.nogoDelete` | `x1..y2` / `id` | no-go lines |
| `map.undo` | | undo the last user edit |
| `map.clearDropoffs` | | remove remembered drop-offs |
| `bot.get` / `bot.set` / `bot.calibrate` | `profile` / `id` | Bot page (the profile's `pins` carry the motor driver and lidar wiring) |
| `wiring.testMotor` | `motor` (a / b), `dir` (1 / -1) | run one motor for half a second |
| `log.start` / `log.stop` | | sensor log (GPS, compass, pose) |

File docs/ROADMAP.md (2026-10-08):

# TankBot Platform roadmap

Last updated: 2026-10-06

## Vision

A robot platform that scales with what is plugged into it. The bare minimum (ESP32, motor driver,
chassis) is a drivable robot. Everything added on top, from bumper switches to a smartphone brain
and a lidar, is recognised and used automatically. Any chassis, any sensor layout, one setup flow
that a newcomer can follow.

## Capability tiers

| Tier | Hardware | What you get |
|---|---|---|
| Drive | ESP32 + motor driver + chassis | Manual driving from the ESP32's own web page (buttons, joystick, keyboard) |
| Reflexes | + bumpers, ToF, ultrasonic | Bump back-off, close-obstacle stop, cliff stop, directional blocks. Runs on the ESP32, no phone needed |
| Brain | + a phone or tablet running the app (mounted or in hand) | Full controller, position tracking, the robot's status face |
| Mapping | + lidar | Maps, map modes, relocalisation, Set position, Go to, autonomous exploration |
| 3D awareness | + depth camera (LiDAR iPhones) | Low obstacles and drop-offs the 2D lidar misses |

## Decisions

- **Bot profile is the single source of truth** for geometry (see `bot-profile.md`). The ESP32 keeps
  its own hardware table (pins, roles, reflex settings); the brain merges it with measured positions.
- **The brain is a role, not a device.** One app: Mounted brain, Brain in hand, Controller.
- **Safety chain never depends on the brain:** ESP32 watchdog + on-board reflexes always apply.
  Every autonomous behaviour runs its own obstacle checks regardless of manual settings.
- **The map is precious.** It changes deliberately (Explore), slowly and only for persistent changes
  (Maintain), or not at all (Off). Doubtful positions never write to it; restore points make any
  mistake undoable.
- **Measure, don't guess.** Trip logs, position events and sensor logs exist so behaviour problems are
  diagnosed from data (see `diagnostics.md`).
- **The user supervises autonomy.** Without a cliff sensor, exploring needs an explicit
  acknowledgment each time; a controller must stay connected for any self-driving.

## Done

- **Phase 1: Bot profile + Bot page.** Profile v2 (platform height, platform-relative sensor
  heights), one editor for every sensor (slot, role, facing, thresholds, placement, live reading).
- **Phase 2: Modular firmware v3.** Generic sensor table in flash, directional reflexes, configurable
  bumper back-off, sensor feed, capability announce, brain announce, `tankbot.local/brain` redirect.
- **Phase 3: App around roles.** Mounted brain / Brain in hand / Controller; per-robot storage;
  guardian fusing every sensor from its profile position; capability tiers; landscape or portrait
  phone mounting; brains on phones without depth sensors (iPhone SE) with automatic fallbacks.
- **Controller redesign.** One consistent shell, pan/zoom/follow map, legend, status cards and toasts,
  Set position, restore points, Settings that save as you go.
- **Mapping.** Pose-graph map straightening (driving links, loop links, wall alignment, GPS when
  good), mapping modes Explore / Maintain / Off, self-cleaning bump and drop-off marks, restore
  points, trust gating (only confident scans are drawn).
- **Navigation.** Planner + follower with steering while driving, pulsed turns with settling,
  recovery when blocked (mark, back up, re-plan), stall detection, standing still when unsure.
- **Autonomous exploration** (first version): frontiers with gap closing, room-first ordering,
  reachability, previews, settle pauses in new territory, automatic stop and rollback when lost.
- **Tracking robustness.** Camera glitch filter, distrust of a drifting camera (lidar-only fallback),
  wide lidar re-search, no relocalisation jumps while self-driving, no lidar corrections from scans
  smeared by fast spins, Settings choice of camera + lidar or lidar only.
- **Diagnostics.** Trip recorder, position events log, sensor/GPS/compass log, analysis tools.
- **Wiring tools.** Bot > Wiring: pin map, default or custom pins, checks in the controller and the
  firmware, motor tests and live readings. The robot page shows how to reach the robot.
- **Lidar + gyro tracking** for phones whose camera struggles; a broken camera is benched
  automatically; Set position searches every heading.
- **The app** asks for its role on every launch and keeps one brain per robot.
- **Interchangeable brains.** The robot keeps its robot-level settings (newer side wins) and a compact
  copy of the most recent map (~40 KB for a whole house); a new brain picks both up on connect.

## Next (in priority order)

1. **Battery monitoring.** Voltage divider into an ESP32 ADC pin, battery level in telemetry, a
   low-battery warning, and self-driving heading home before it browns out (2026-10-06 ended on a
   flat battery).
2. **Exploration robustness on the SE.** Compare camera + lidar against lidar only on the same runs
   (trip logs + events); make the better one the default for phones without a depth sensor.
3. **Phone torch as headlights** (Auto / On / Off from the phone's light estimate and camera drift).
4. **Help tab in the controller** (the user guide, with drawn examples), linked from every page.
5. **Cliff sensor.** Wire the TOFSense-F2 Mini (T to GPIO32, R from GPIO33, 5 V), aim it at the floor,
   calibrate; removes the exploration acknowledgment.
6. **Rear sensing.** A rear bumper or ultrasonic so recovery back-ups can't nudge something behind.
7. **IMU + encoder fusion** for tracking without a camera and better stall detection.
8. **ARKit place memory** (world maps) as a relocalisation booster on iPhones.
9. **Second robot:** wheelchair-base profile; prove everything carries over.
10. **Wired brain option** (iPhone 12 Pro via USB Ethernet + an on-board travel router).

## Always

- Test-drive between steps; nothing regresses. `flutter test` must pass before every install.
- Commit each working change with a message that says why, push, and keep these docs current.

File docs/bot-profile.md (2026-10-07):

# Bot profile

The bot profile describes one robot: its size, how it drives, where every sensor sits, and the
settings that belong to that robot. All software (tracking, mapping, navigation, safety, the
controller's drawings) reads from it. Nothing about a specific robot is hard-coded.

Edit it on the controller's **Bot** page; **Save to robot** stores it on the brain and sends the
robot-side sensor table to the ESP32 (which restarts once to apply it).

## Coordinates

- Positions on the platform: **from the front edge** (`fromFrontMm`, negative = sticking out ahead)
  and **from the left edge** (`fromLeftMm`), seen from above with the front at the top.
- Heights (`heightMm`): **above the platform top** (negative = below it). The platform's own height
  above the floor is `platform.heightMm`.
- Internally: robot frame **x forward, y left**, origin at the platform centre.
- `yawDeg`: facing direction, 0 = forward, positive = turned left.

## Format (version 2)

```json
{
  "version": 2,
  "name": "TankBot",
  "drive": "tank",                                  // tank | wheelchair | mecanum
  "phoneMount": "portrait",                         // portrait | landscape
  "platform": { "widthMm": 185, "lengthMm": 170, "heightMm": 66 },
  "minPower": 0.8, "cruisePower": 0.9,              // the lowest power that moves it; its best driving power
  "mapping": { "mode": "maintain", "tracking": "auto", "wallAlign": true, "gpsMaxAccM": 5 },
  "sensors": [
    { "id": "lidar", "type": "lidar",      "fromLeftMm": 98,   "fromFrontMm": 65,    "heightMm": 200,  "slot": "LIDAR", "role": "mapping" },
    { "id": "cam",   "type": "camera",     "fromLeftMm": 110,  "fromFrontMm": 38,    "heightMm": 135 },
    { "id": "us1",   "type": "ultrasonic", "fromLeftMm": 70,   "fromFrontMm": 3.5,   "heightMm": 13.5, "slot": "US1",   "role": "obstacle", "stopMm": 150 },
    { "id": "bump1", "type": "bumper",     "fromLeftMm": 92.5, "fromFrontMm": -17.5, "heightMm": -28,  "slot": "BUMP1", "role": "bump", "widthMm": 160, "backoffMs": 150 }
  ]
}
```

Also stored: safety distances (stop, pass, depth stop, depth height), `hardwareDirty` (local sensor
edits the robot hasn't confirmed yet) and `hardwareMigrated` (the one-time carry-over of old measured
positions onto the robot's table has happened).

## Sensors

Types: `lidar`, `camera` (the phone camera: where camera tracking sits), `depth`, `bumper`, `tof`,
`ultrasonic`, `imu`.

Robot-side fields (they live in the ESP32's table too): `slot` (BUMP1/BUMP2/TOF/US1/US2/I2C/LIDAR),
`role` (`obstacle`, `cliff`, `bump`, `orientation`, `mapping`, `none`), `enabled`, `yawDeg`,
`floorTilt` (aimed at the floor), `stopMm` (obstacle role), `floorMm` (calibrated floor distance,
cliff role), `backoffMs` (bump role: reverse this long after a hit, 0 = just stop).

A sensor with role `cliff` counts as a drop-off sensor (exploring then needs no acknowledgment).

## Merging with the robot

On connect the brain reads the robot's table, keeps its own measured positions for those sensors,
and pushes back any difference. The brain never merges into, or saves, a profile before the saved one
has loaded from storage.

## Derived

- **Body radius** (half the platform diagonal) and **inflation** (body radius + pass distance) for
  planning and exploration reachability.
- **Front edge and half-width** for the guardian's forward-clear decision.
- **Lidar offset** from the tracked point, and every sensor's frame for live readings.

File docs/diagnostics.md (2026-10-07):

# Diagnostics

When the robot misbehaves, look at data before changing code. The brain keeps three kinds of log in
its app container (`Documents/logs/`).

| Log | Written | Contents |
|---|---|---|
| `nav_YYYYMMDD_HHMMSS.csv` | automatically, one per Go To / exploration leg | every driving step (10 Hz): decision and why, pose, target, heading error, motor command, guardian verdict, re-plans, the robot's motor state and watchdog count, scan age, tracking mode, event-loop lag |
| `events_YYYYMMDD.csv` | automatically, whenever the position changes by anything other than driving | relocalisations, Set position, tracking switches (camera + lidar / lidar only), camera jumps and drift, lidar snaps, wide-search fixes, map straightening > 20 cm, rollbacks |
| `log_YYYYMMDD_HHMMSS.csv` | Settings > Sensor log | GPS fixes, compass readings, pose at 5 Hz |

## Getting the logs onto the Mac

```bash
xcrun devicectl device copy from --device <device id> \
  --domain-type appDataContainer --domain-identifier com.johnsonfarms.tankbotBrain \
  --source Documents/logs --destination ~/tankbot-work/logs/<phone>
```

(`xcrun devicectl list devices` shows the ids.) The same command with `--source Documents/robots`
backs up profiles and maps; `copy to` puts files back.

## Tools (`tools/`)

| Tool | Use |
|---|---|
| `analyze_nav.py <nav.csv>` | where the time went, motor starts and bursts, what interrupted driving, re-plans, turn reversals, timing health, watchdog stops |
| `analyze_sensor_log.py <log.csv>` | GPS accuracy and drift against the tracked path; compass error by place |
| `brain_send.py '<json>'` | send one controller message to the brain and print the result (e.g. `{"type":"explore.preview"}`) |
| `nopath_check.py` | rebuild what the planner sees and show what boxes the robot in |
| `cdp_check.py <url> [seconds] [js]` | load the controller in headless Chrome and query it (layout and error checks) |
| `lidar_client.py` | live lidar plot from the robot |

## What we learned the hard way (2026-10)

- **Manual drive re-apply fought Go To** (commanded stop 10x a second): found by the trip recorder
  showing motors off 70 % of the time while commanded forward.
- **Pulsed full-power turning overshot and reversed** (the left-right wave): turn reversals in the log.
- **The robot spins at 200+ deg/s**; scans taken while spinning are smeared and can match 90/180 deg off.
- **iPhone SE camera tracking drifts in dim rooms**, even standing still: events log shows camera drift
  with idle motors. Lights on helps; the lidar-only fallback covers it.
- **Indoors GPS is useless** (2.6 m typical, 10 m worst) and the compass is 20-40 deg off near the
  motors: `analyze_sensor_log.py` on a recorded drive.
- **A flat battery looks like a software hang**: robot unreachable, lidar stale, no reflex events.

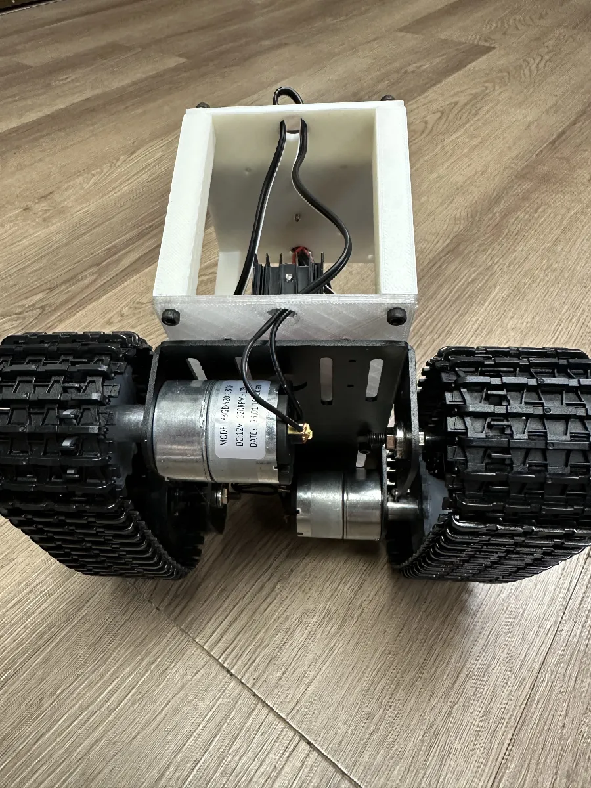
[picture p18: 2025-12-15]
firmware/motion/images/tankbot-undercarriage.webp

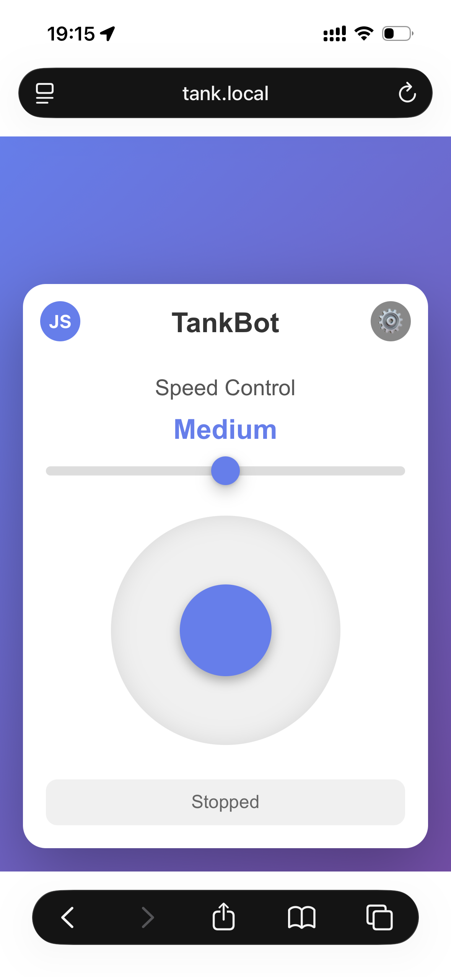
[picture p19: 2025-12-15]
firmware/motion/images/tankbot-interface-joystick.PNG

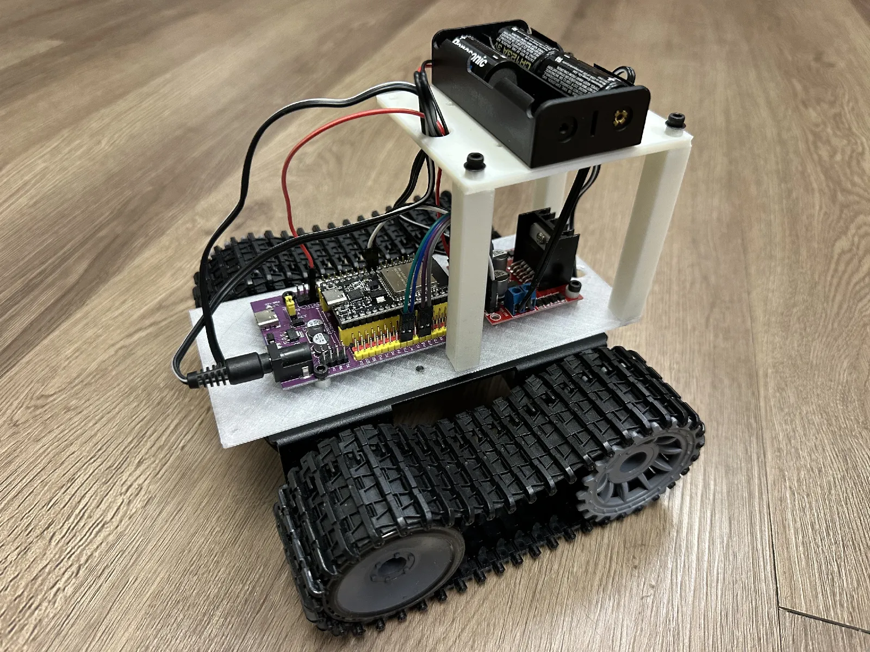
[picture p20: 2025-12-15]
firmware/motion/images/tankbot-left.webp

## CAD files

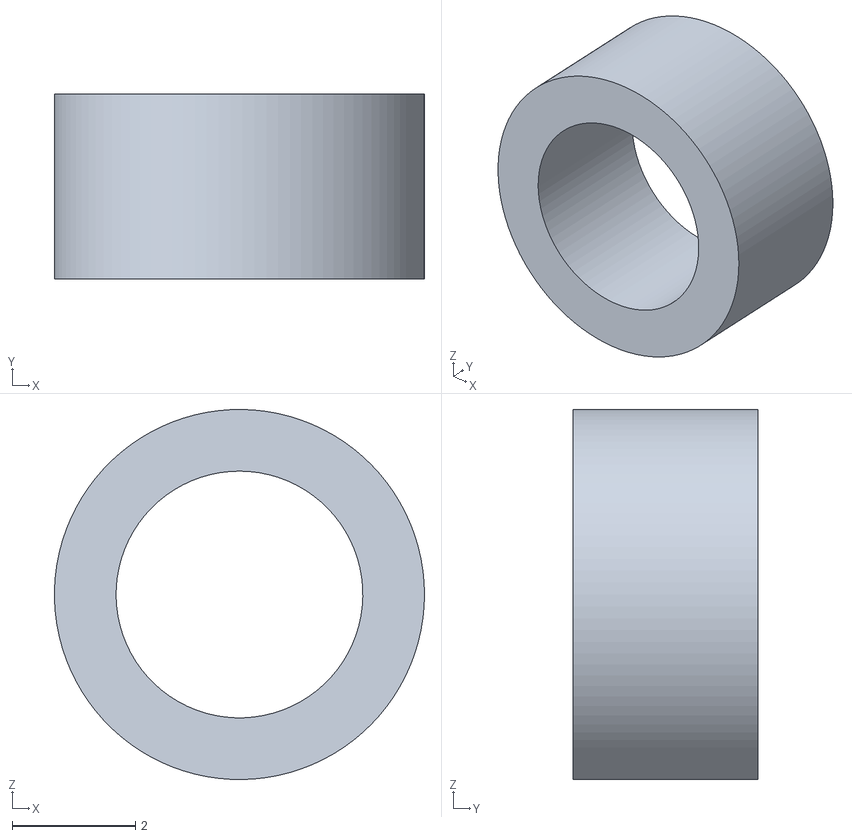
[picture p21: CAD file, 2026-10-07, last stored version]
hardware/3d-models/TankBot Spacer 6x3x3.stl
6.00 x 3.00 x 6.00

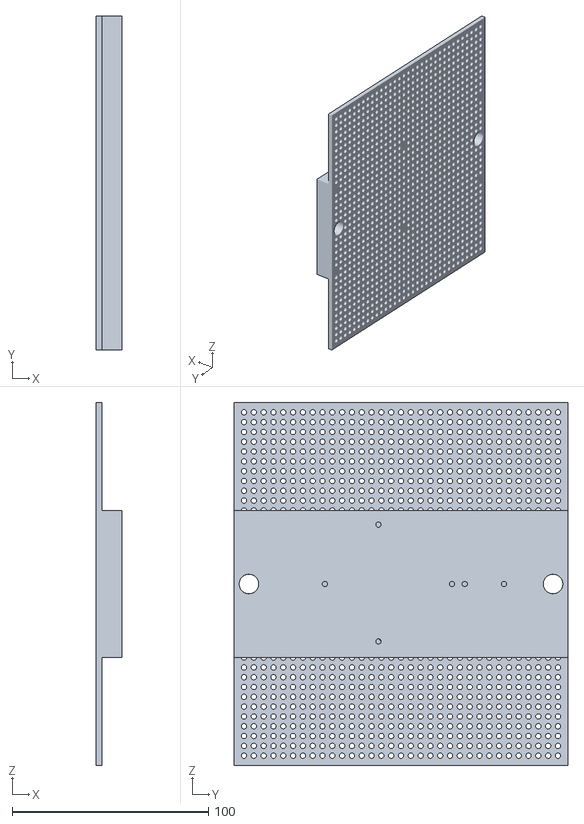
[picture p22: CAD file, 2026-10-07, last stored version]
hardware/3d-models/TankBot Base.stl
13.0 x 170.0 x 185.0

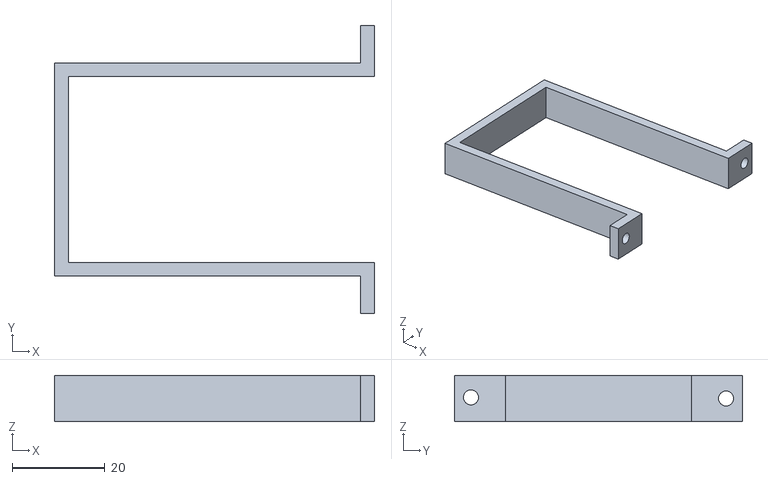
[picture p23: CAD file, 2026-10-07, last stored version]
hardware/3d-models/TankBot Battery Clamp.stl
69.0 x 62.0 x 10.0

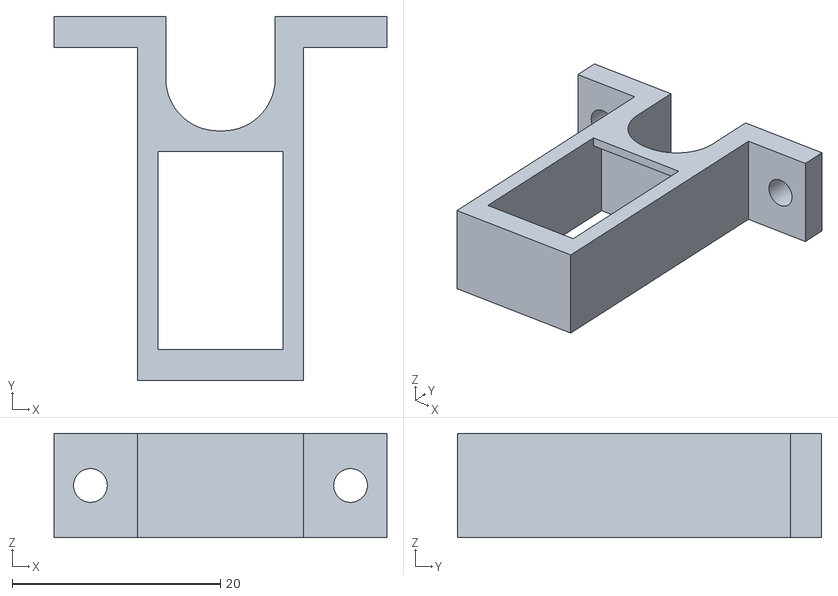
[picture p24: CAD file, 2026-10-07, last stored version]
hardware/3d-models/TankBot Charger Clamp with Switch.stl
32.0 x 35.0 x 10.0

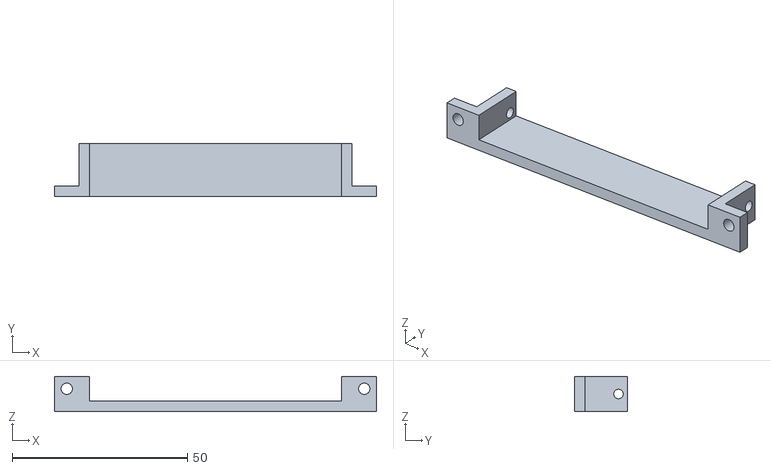
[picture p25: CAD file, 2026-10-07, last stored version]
hardware/3d-models/TankBot Phone Base.stl
92.0 x 15.0 x 10.0

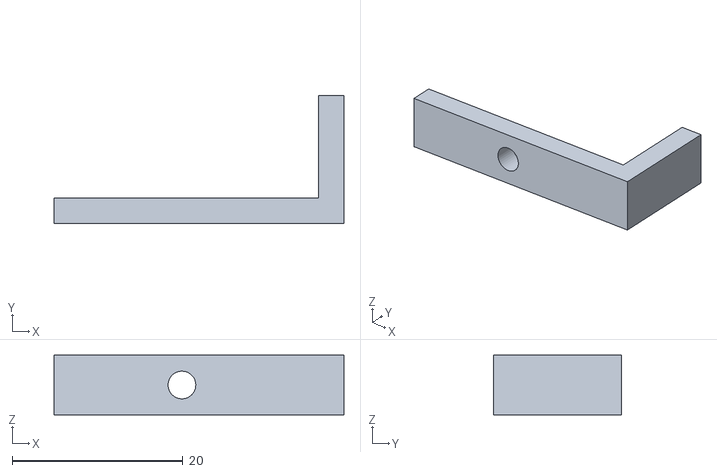
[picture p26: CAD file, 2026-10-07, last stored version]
hardware/3d-models/TankBot Ultrasonic Mount 2of2.stl
34.0 x 15.0 x 7.00

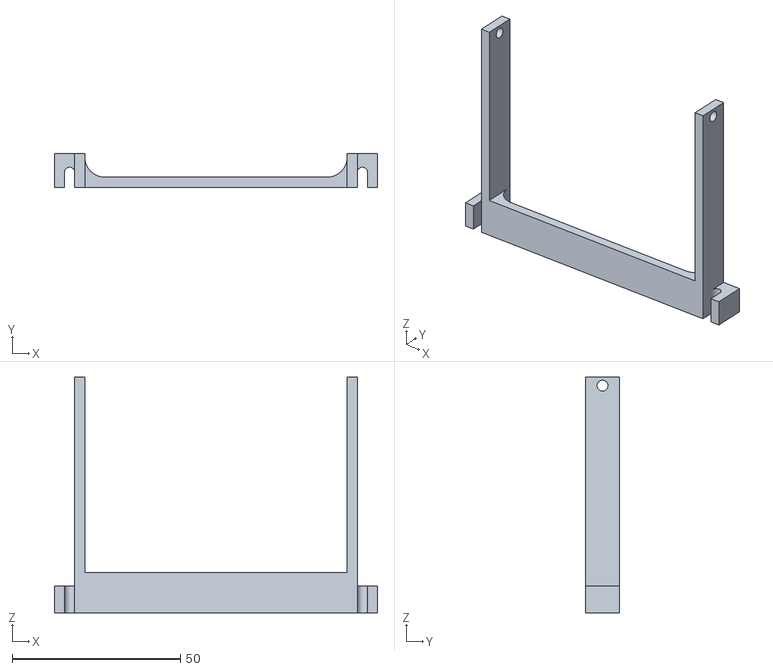
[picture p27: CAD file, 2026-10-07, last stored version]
hardware/3d-models/TankBot Phone Clamp.stl
96.0 x 10.0 x 70.0

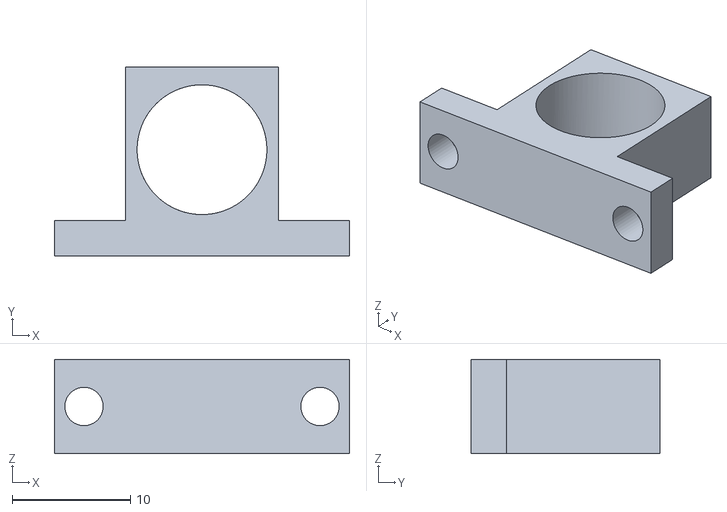
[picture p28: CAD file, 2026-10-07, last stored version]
hardware/3d-models/TankBot Wire Management.stl
25.0 x 16.0 x 8.00

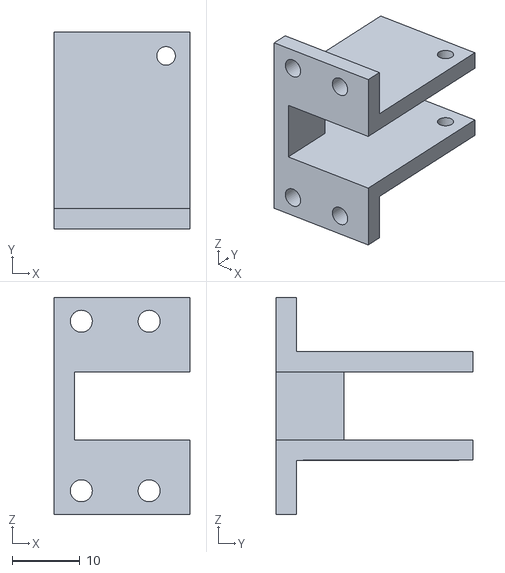
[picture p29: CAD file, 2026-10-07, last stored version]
hardware/3d-models/TankBot Bumper Switch Mount.stl
20.0 x 29.0 x 32.0

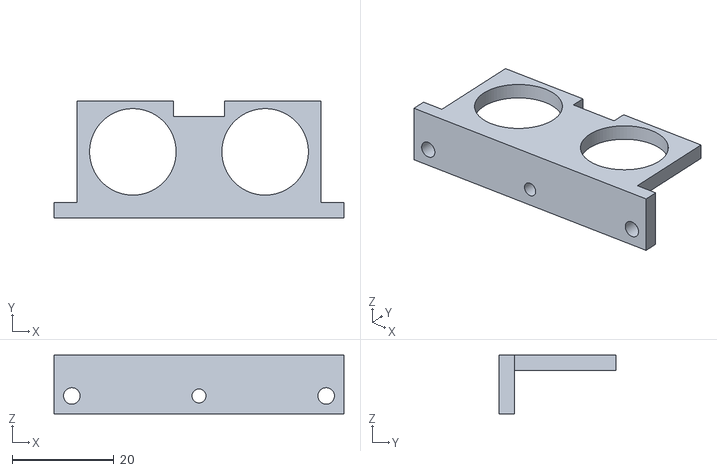
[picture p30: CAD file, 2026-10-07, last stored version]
hardware/3d-models/TankBot Ultrasonic Mount 1of2.stl
57.0 x 23.0 x 11.5

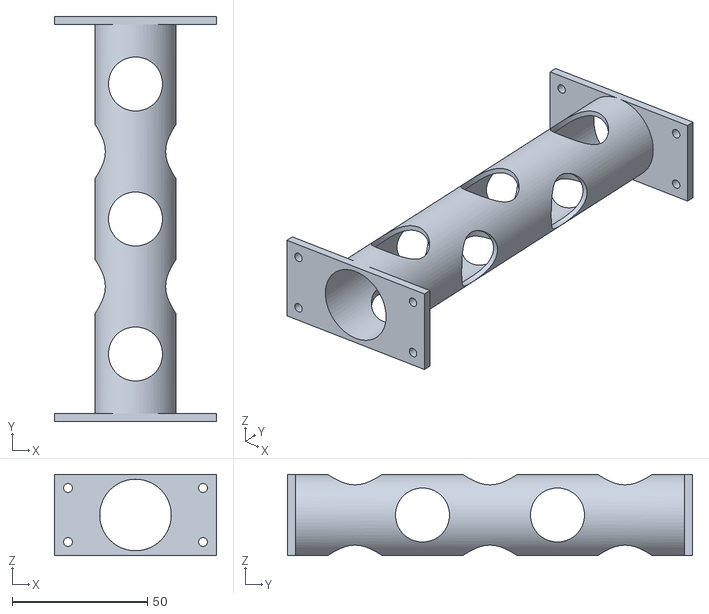
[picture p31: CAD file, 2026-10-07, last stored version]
hardware/3d-models/TankBot Lidar Tower.stl
60.0 x 150.0 x 30.0

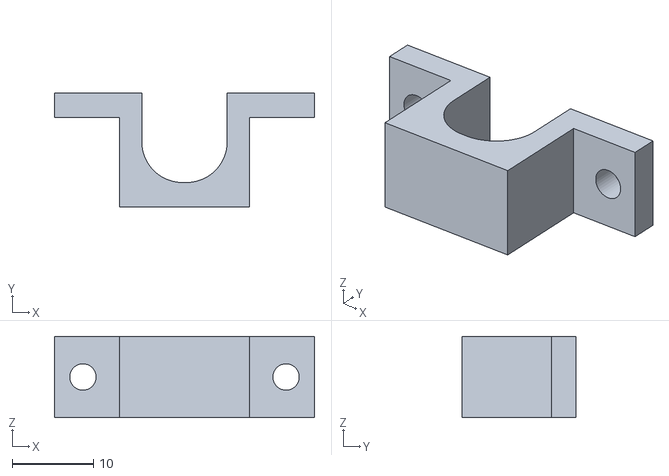
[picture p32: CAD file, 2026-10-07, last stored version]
hardware/3d-models/TankBot Charger Clamp.stl
32.0 x 14.0 x 10.0

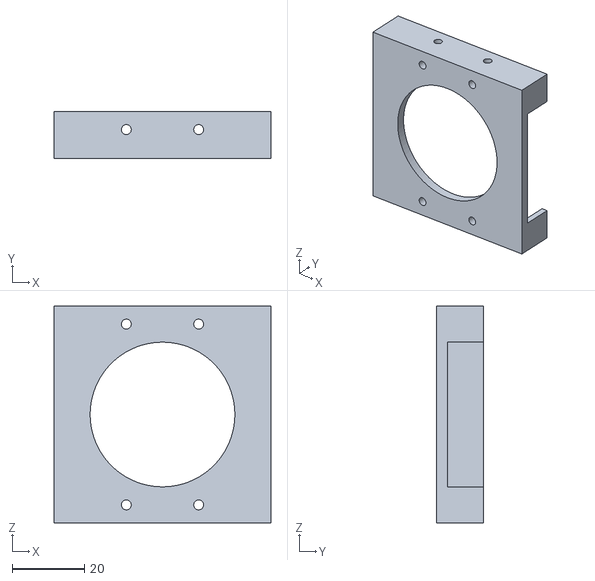
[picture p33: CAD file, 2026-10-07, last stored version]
hardware/3d-models/TankBot Lidar Base.stl
60.0 x 13.0 x 60.0

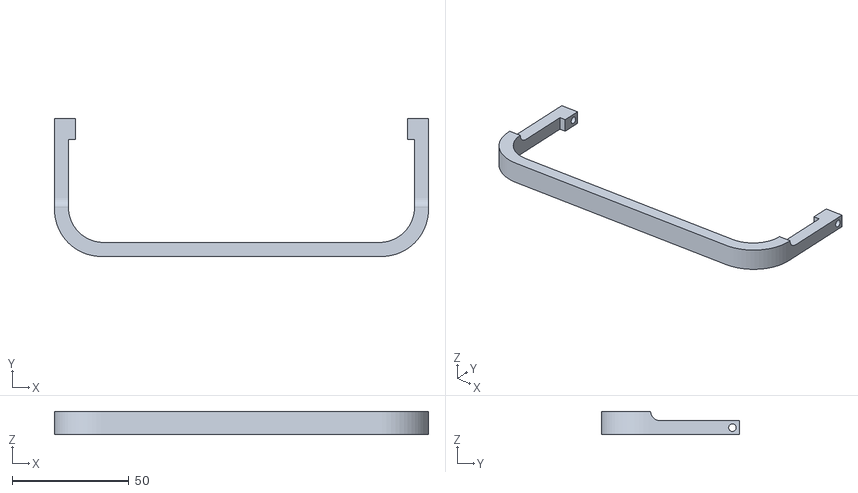
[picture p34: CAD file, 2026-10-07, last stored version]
hardware/3d-models/TankBot Bumper for Switch.stl
160.0 x 59.0 x 10.0

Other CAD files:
hardware/3d-models/TankBot Connector 2-Wire.stl
hardware/3d-models/TankBot Base.f3d
hardware/3d-models/TankBot Battery Clamp.f3d
hardware/3d-models/TankBot Bumper Switch Mount.f3d
hardware/3d-models/TankBot Bumper for Switch.f3d
hardware/3d-models/TankBot Charger Clamp with Switch.f3d
hardware/3d-models/TankBot Charger Clamp.f3d
hardware/3d-models/TankBot Connector 2-Wire.f3d
hardware/3d-models/TankBot Lidar Base.f3d
hardware/3d-models/TankBot Lidar Tower.f3d
hardware/3d-models/TankBot Phone Base.f3d
hardware/3d-models/TankBot Phone Clamp.f3d
hardware/3d-models/TankBot Ultrasonic Mount 1of2.f3d
hardware/3d-models/TankBot Ultrasonic Mount 2of2.f3d
hardware/3d-models/TankBot Wire Management.f3d

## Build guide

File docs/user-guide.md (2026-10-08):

# User guide

How to drive, map and explore with a TankBot-platform robot and a phone brain.

## Getting to the controls

| Address | What |
|---|---|
| `http://tankbot.local/` | the robot's own page: always works, even without a brain. Buttons, joystick, arrow keys / W A S D (Space stops), speed, trim, **Setup** |
| `http://tankbot.local/brain` | **bookmark this.** Takes you to the brain's full controls wherever the brain is |
| the app, Controller role | the same full controls on a phone |

The robot's page shows **Open full controls** whenever a brain is running. Its **gear** panel (where
the steering trim is) shows how to reach the robot right now: its address, name, Wi-Fi and signal,
the brain's address and the firmware version, looked up live each time it opens. Handy when
`tankbot.local` doesn't work on a device, or after the router hands out new addresses.

When the app opens it asks what this device is doing today (Mounted brain, Brain in hand,
Controller), with last time's choice highlighted. It checks the robot first: if another device is
already the brain, it suggests Controller (connected to that brain). Only one brain per robot: a
brain that notices a second one shows a red card and won't drive itself until one is closed.

## The full controls

The top bar on every page: robot name, status lights (**Brain**, **Robot**, **Lidar** scans/s,
**Position**, **Map** mode), the tabs, and a link to the robot's page. Green is good, amber means
working on it, red needs attention.

### Drive page

**The map**: drag to look around, scroll or pinch to zoom, **+ / -**, **(o)** to follow the robot again,
**Radar** for the robot's-eye view, **Key** for the colour key:

| On the map | Meaning |
|---|---|
| teal | walls (the map) |
| grey | open floor (the map); black is unexplored |
| yellow dots | what the lidar sees right now (should sit on the teal walls) |
| orange squares | low obstacles from the depth camera (phones with a depth sensor) |
| teal dots | ultrasonic / ToF readings right now |
| red lines | no-go lines |
| orange rings | bumps and stalls; dashed = temporary (fade in 15 min), solid = confirmed |
| red rings | drop-offs; dashed / solid as above |
| blue line and circle | the route and goal |
| purple diamond | the next place exploration will go |
| white circle with a line | the home spot (where the map started) |
| orange arrow | the robot (grey when it isn't sure where it is) |

**Status cards** (top left) say what the robot is doing or needs, with buttons: Stop, Try again,
Set position, I'm at home. Short confirmations appear at the bottom and fade.

**Panel**: joystick, **Stop**, max speed, **Go to...** (then click the map; you can drag and zoom
first), **Edit map** (move, eraser, no-go lines, undo), **Set position...**, **New map here**, and
**Mapping**: Explore / Maintain / Off.

Keyboard: arrows or W A S D drive, Space stops, Esc cancels. Leaving the page stops the robot.

### Mapping modes

| Mode | Use it for | What happens to the map |
|---|---|---|
| **Explore** | building a map, adding rooms, after moving furniture | everything you drive past is added. Saves a restore point when you switch to it |
| **Maintain** (default) | everyday driving | grows into unmapped areas; elsewhere a spot changes only after the change is seen on 3 separate passes over 10+ minutes (moved furniture yes, people and pets no) |
| **Off** | just driving | never changed (it is still used to know where the robot is) |

When the robot drives itself, Explore acts as Maintain, except during autonomous exploration.

### Exploring on its own

1. Set **Mapping** to **Explore**. **Explore on its own** appears below.
2. Without a cliff (drop-off) sensor you are asked to acknowledge that the robot can't detect drops and
   that you'll watch it. Block off stairs or draw no-go lines across them first.
3. It drives to the edges of what it has mapped (its own room first, then through doorways), pausing
   in new areas to let the map form, and drives home when nothing reachable is left. The card says why
   it finished (how many openings it found and why it skipped them).

Stop, the joystick, any drive key or leaving the page ends it. It also stops by itself if the robot
loses track of where it is (removing the last stretch of mapping), stops responding, or after 30 min.

### Set position

When the robot is lost or wrong: **Set position...**, press on the map where it really is and drag
toward the way it faces. The lidar fine-tunes the placement. A tap without dragging keeps its heading.

### Maps page

Save, rename, load, delete maps; **Find me again**, **I'm at home**; **Clear remembered drop-offs**;
**Restore an earlier version** (restore points from before Explore mode and before exploring).
The quality line shows lidar corrections, loop closures, straightening and what Maintain is doing.

### Bot page

The robot's size, drive type, how the phone is mounted (upright or on its side) and every sensor:
what it is plugged into, what it's used for, which way it faces, where it sits, its live reading.
Drag sensors in the top and side views. **Save to robot** sends sensor changes to the robot.

The **Wiring** switch at the top of the Bot page shows how each part connects to the ESP32: a map of
the expansion board's pins, Default or Custom pins for the motor driver, the lidar and every sensor
(only pins that can do the job are offered), checks that block saving a wiring that can't work, and
Test buttons (run each motor briefly, watch each sensor's live reading). Details in
[wiring.md](wiring.md).

### Settings

Changes save as soon as you leave a field (a "Saved" note confirms it).

- **Driving**: steering trim, minimum power to move, cruise power.
- **Safety**: obstacle stop, stop and pass distances, depth camera stop distance and height.
- **Position tracking**: camera + lidar (lidar alone when the camera drifts or jumps) or lidar only.
  Lidar only uses the phone's gyro for turning and the lidar for everything else; it's the steadier
  choice on phones without a depth sensor or when the camera struggles.
- **Map straightening**: wall alignment; use GPS when better than N metres (outdoors).
- **Robot / This brain**: what is attached and what the phone can do.
- **Sensor log**: record GPS, compass and position for testing.

## Changing brain phones

The robot keeps what a new brain needs: its sensors (positions, roles, thresholds), its robot-level
settings (platform size, safety distances, power levels, mapping and tracking preferences) and a
compact copy of the most recent map (walls, open floor, no-go lines, edits). A new brain picks all of
it up when it connects and, if it has no map of its own yet, loads the robot's map and finds itself
on it. Measure the new phone's camera position on the Bot page; that one is per phone.

The robot's copy updates when the map changes meaningfully (at most every 5 minutes, never while the
robot drives itself). The Maps page shows what the robot holds. Full maps, with their raw scans for
straightening, stay on the brain.

## Troubleshooting

| You see | Try |
|---|---|
| **Robot not responding** / no lidar | check the battery and power; the brain reconnects by itself |
| yellow dots don't line up with the walls | **Set position** |
| "Camera tracking is drifting here" | normal in dim rooms or with plain walls; the lidar takes over. Turning the lights on helps |
| the map got messy | **Maps > Restore an earlier version** |
| Go to says there's no path | look for rings or no-go lines boxing it in; the eraser removes marks |
| exploring went home at once | read the reason on the card (openings found and why they were skipped); check its position |
| the robot keeps stopping in front of something | it backs up and goes around by itself; after 4 tries it gives up on that spot |
| it drives but doesn't move (caught on something low) | detected after ~2 s: marked and backed away from automatically |
| it can't find the brain | open `tankbot.local/brain`; on the brain phone check Wi-Fi and Settings > Privacy > Local Network |
| you need the robot's address | `tankbot.local`, gear icon: the address is at the bottom |
| a sensor never reports, or "The robot didn't start it" | Bot > Wiring: the card says what's wrong with its pins |
| a track runs the wrong way or the wrong track moves | Bot > Wiring > Motor driver: Test, then Swap A and B or Reverse A / B |

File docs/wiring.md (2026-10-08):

# Standard wiring (ESP32 DevKit, 38-pin)

The default pin map baked into the firmware. If your build differs, change it in the controller's
**Bot > Wiring** view (see *The Wiring view* below).

| Function | ESP32 pin | Notes |
|---|---|---|
| Motor driver (L298N) | IN1 16, IN2 17, IN3 18, IN4 19, ENA 25, ENB 26 | ENA/ENB jumpers removed |
| Lidar (RPLidar C1, UART2) | lidar TX -> 4, lidar RX <- 27 | 5 V power, 3.3 V logic |
| ToF (TOFSense-F2 Mini, UART1) | ToF T -> 32, ToF R <- 33 | 5 V power (4.3-5.2 V), 3.3 V logic, 921600 baud. JST GH 1.25 mm connector |
| Ultrasonic (HC-SR04P / RCWL-1601) | TRIG 14, ECHO 34 | power from 3.3 V so ECHO is 3.3 V. A plain 5 V HC-SR04 needs a divider on ECHO (1 k / 2 k) |
| Bumper left | 13 to COM, NC to GND | internal pull-up; normally-closed = fail-safe |
| Bumper right | 23 to COM, NC to GND | internal pull-up; normally-closed = fail-safe |
| I2C (future IMU) | SDA 21, SCL 22 | reserved |
| Status LED | 2 (onboard) | |

Pins 0, 2, 5, 12 and 15 affect booting and are not used for anything that could be held at power-up.
Pins 34-39 are input-only (fine for ECHO).

## Power

**Power as built:** the 3S battery (9-12.6 V) goes through the rocker switch to the expansion board's
DC input and to the L298N's 12 V input (the battery kit's lever connectors and barrel-to-terminal adapters
make the joins). The expansion board's 5 V powers the lidar; the ultrasonic runs from 3.3 V.

**Recommended:** feed the 5 V rail (lidar, ToF) from a 12 V to 5 V buck converter (2 A or more) instead of
the expansion board's onboard 5 V. That is a small linear regulator: from a 12 V battery it turns several
volts into heat, runs hot with the lidar and the ESP32 on it, and an overheating regulator browns out the
ESP32.

## Sensor jobs

- **Bumpers:** last line of defence. A hit stops the motors on the ESP32 itself, backs off briefly,
  and blocks forward motion until released.
- **ToF (narrow beam):** cliff / drop-off sensor. Mount low at the front, angled down to look at the
  floor 15-25 cm ahead, then press "Calibrate ToF floor" on the setup page. If the floor reading
  jumps much longer (or disappears), forward motion is blocked.
- **Ultrasonic (wide cone):** low obstacles ahead that the lidar's scan plane misses. Forward motion
  is blocked closer than the stop distance (default 150 mm).

## Robot-side data

- `http://tankbot.local/api/capabilities` : what is attached and how it is wired (JSON)
- `http://tankbot.local/api/sensors` : live readings (JSON)
- UDP 5603: send `TSSUB` (repeat every few seconds); receive `TCAP1`+JSON once, then `TSN1`+JSON at 20 Hz

## Defaults for more sensors

Each sensor type has default pins, given in order as you add sensors on the Bot page:

| Sensor | 1st | 2nd |
|---|---|---|
| Bumper | P13 | P23 |
| Ultrasonic | TRIG P14, ECHO P34 | TRIG P2, ECHO P35 (P2 is a boot pin: fine for a trigger) |
| ToF (serial) | T P32, R P33 | (one serial port: one ToF) |
| I2C (IMU) | SDA P21, SCL P22 (shared by all I2C parts) | |

Beyond these, choose **Custom** pins.

## The Wiring view

Controller > **Bot** > **Wiring**: how every part connects to the ESP32.

- **Pin map:** the expansion board's two header columns as printed, each used pin labelled with
  what's on it; flash, USB-serial and power pins greyed out; conflicts red, boot pins amber.
- **Pin budget:** how many of the 24 usable pins are in use.
- **Default or Custom** for the motor driver, the lidar and each sensor. Custom pickers only offer pins
  that can do the job (34, 35, 36 and 39 are inputs only).
- **Checks** before saving: two parts on one pin, an output on an input-only pin, flash or USB-serial
  pins, more than one ToF, a pin left unchosen. Boot pins (0, 2, 5, 12, 15) get a caution.
- **The robot checks too:** at startup it refuses to start a sensor whose wiring can't work, and the
  view shows why ("The robot didn't start it: pin 34 is input-only"). Everything else keeps running.
- **Tests:** motor A / B forward and back for half a second (A forward should drive the left track
  forward; **Swap A and B** and **Reverse A / B** fix it if not), and live readings for each sensor
  (press the bumper, wave a hand in front of the ultrasonic).

Save sends the wiring to the robot, which restarts once to apply it.

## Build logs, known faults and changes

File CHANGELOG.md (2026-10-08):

# Changelog

## v0.4 (2026-10-07)

Interchangeable brains, the Wiring view, lidar + gyro tracking, and a public release.

- **Interchangeable brains:** firmware stores robot-level settings (`/api/settings`) and a compact
  map (`/api/map`, LittleFS, chunked all-or-nothing uploads); the brain syncs settings (newer wins),
  keeps the robot's map copy fresh and starts from it when it has no map. Maps can start from a grid.
- Defaults that drive well: stop 100 mm, pass 50 mm, depth 100/40 mm, platform height 66 mm.
- Fixed the flickering Robot not responding card.
- iPhone 11 Pro as a brain; new app icon.
- The app asks for its role on every launch (last choice highlighted), checks whether the robot
  already has a brain and suggests Controller; a running brain that sees a second brain warns and
  won't self-drive.
- **Wiring view** (Bot > Wiring): the expansion board's pin map, a pin budget, Default or Custom pins
  for the motor driver, lidar and each sensor, checks that block impossible wiring, motor tests,
  swap / reverse helpers and live readings. Firmware 3.1 validates the wiring at startup (miswired
  sensors aren't started and say why) and adds `/api/test/motor`.
- The robot page's gear panel shows the robot's address, name, Wi-Fi and signal, brain and firmware
  (`/api/info`).
- **Lidar + gyro tracking:** in lidar-only mode turning comes from the phone's raw gyro; no freezing
  on missed scans; a camera making impossible jumps is benched for a minute and ARKit restarted;
  autofocus locked; Set position searches every heading.
- The app is called **TankBot**; the README has media, a parts list and build steps; the model files
  are a backup zip next to the Printables link.
- Security: hotspot password in `secrets.h`, a pre-commit secret check, `SECURITY.md`; history
  cleaned of an upload log and an old key before going public.

## v0.3 (2026-10-06)

Firmware v3 and a brain that maps, navigates and explores on its own.

**Robot (firmware v3)**
- Generic sensor table in flash (any number of bumpers and rangers in any direction), directional
  reflexes, per-bumper back-off duration (default 150 ms, 0 = just stop).
- Sensor feed (`TSSUB`/`TCAP1`/`TSN1`), brain announce (`TBRN1`), `/api/brain` and the
  `tankbot.local/brain` redirect; keyboard driving and links on the robot's own page.

**Controller**
- Redesign: one shell with status lights, pan/zoom/pinch/follow map, colour key, scale bar, status
  cards and toasts, phone layout. Moved into `assets/controller.html`.
- Set position, restore points, mapping mode selector, exploration controls, tracking choice,
  Saved confirmations, Robot not responding card.

**Mapping**
- Pose graph straightening (Levenberg-Marquardt, skyline solver): driving and loop links, wall
  alignment, GPS only when better than a threshold and spread over 15 m.
- Mapping modes Explore / Maintain (default) / Off; Maintain writes only persistent changes and
  extends into unmapped ground.
- Bump, stall and drop-off marks are temporary unless they recur; drop-off detection rejects glossy
  floor reflections; eraser removes marks; undo only undoes user edits.
- Trust gating: doubtful scans are never drawn. Restore points before Explore / exploring.

**Navigation and exploration**
- Fixed the Go To stutter (manual drive re-apply commanded stop 10x/s during autonomous driving).
- Steering while driving, pulsed turns with settling, calmer re-planning.
- Recovery when blocked (mark, back up, re-plan), stall detection, standing still when unsure.
- Autonomous exploration: frontiers with gap closing, rooms first, reachability, previews, settle
  pauses, rollback when lost, confirmed "nothing left", reasons on finish; cliff-sensor acknowledgment.

**Tracking**
- Robot link finds and re-finds the robot (retry, last address, reconnect after silence).
- Drift handling: wider windows, wide re-search, lidar snap on solid ground, no whole-map jumps while
  self-driving, camera glitch filter, drifting-camera fallback to lidar only, no matching on spin-smeared
  scans; Settings choice camera + lidar / lidar only.
- iPhone SE support (no depth sensor); landscape phone mounting with orientation lock.

**Diagnostics**
- Trip recorder, position events log, GPS/compass sensor log; analysis tools in `tools/`.

**Fixes**
- Startup race that replaced the saved profile with defaults and pushed a default lidar position.
- Mode switch to lidar-only starting from a stale pose (5 m jumps).

## v0.2 (2025-12-23) and earlier

The original TankBot firmware, lidar bridge and first brain app; see the git history.

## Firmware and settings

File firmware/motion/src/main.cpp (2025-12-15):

#include <Arduino.h>
#include <WiFi.h>
#include <WebServer.h>
#include <ESPmDNS.h>
#include <DNSServer.h>
#include <Preferences.h>

// Motor control pins
#define IN1 16  // Left motor direction
#define IN2 17  // Left motor direction
#define IN3 18  // Right motor direction
#define IN4 19  // Right motor direction
#define ENA 25  // Left motor speed (PWM)
#define ENB 26  // Right motor speed (PWM)

// PWM settings
#define PWM_FREQ 1000
#define PWM_RESOLUTION 8
#define PWM_CHANNEL_A 0
#define PWM_CHANNEL_B 1

// Speed levels (0-255)
#define SPEED_SLOW 160
#define SPEED_MEDIUM 220
#define SPEED_FAST 255

// WiFi credentials
const char* ssid = "TankBot";
const char* password = "tankbot2025";

// Web server on port 80
WebServer server(80);

// DNS server for captive portal
DNSServer dnsServer;
const byte DNS_PORT = 53;

// Preferences for persistent storage
Preferences preferences;

// Current speed setting
int currentSpeed = SPEED_MEDIUM;

// Trim adjustment for compensating track tension differences
// Range: -20 to +20 (negative = left motor slower, positive = right motor slower)
int motorTrim = 0;

// Function declarations
void stopMotors();
void moveForward();
void moveBackward();
void turnLeft();
void turnRight();

// HTML page for the web interface
const char MAIN_page[] PROGMEM = R"=====(
<!DOCTYPE html>
<html>
<head>
  <meta name="viewport" content="width=device-width, initial-scale=1.0">
  <title>TankBot Control</title>
  <style>
    * {
      margin: 0;
      padding: 0;
      box-sizing: border-box;
    }

    html, body {
      font-family: Arial, sans-serif;
      background: linear-gradient(135deg, #667eea 0%, #764ba2 100%);
      height: 100vh;
      width: 100vw;
      overflow: hidden;
      position: fixed;
      touch-action: none;
    }

    body {
      display: flex;
      flex-direction: column;
      align-items: center;
      justify-content: center;
      padding: 20px;
    }

    .container {
      background: white;
      border-radius: 20px;
      padding: 30px;
      box-shadow: 0 20px 60px rgba(0,0,0,0.3);
      max-width: 400px;
      width: 100%;
      max-height: 95vh;
      overflow-y: auto;
      touch-action: pan-y;
      position: relative;
    }

    h1 {
      text-align: center;
      color: #333;
      margin-bottom: 30px;
      font-size: 2em;
    }

    .speed-control {
      margin-bottom: 30px;
      text-align: center;
    }

    .speed-label {
      font-size: 1.2em;
      color: #555;
      margin-bottom: 10px;
      display: block;
    }

    .speed-value {
      font-size: 1.5em;
      color: #667eea;
      font-weight: bold;
      margin: 10px 0;
    }

    .speed-slider {
      width: 100%;
      height: 8px;
      border-radius: 5px;
      background: #ddd;
      outline: none;
      -webkit-appearance: none;
    }

    .speed-slider::-webkit-slider-thumb {
      -webkit-appearance: none;
      appearance: none;
      width: 25px;
      height: 25px;
      border-radius: 50%;
      background: #667eea;
      cursor: pointer;
    }

    .speed-slider::-moz-range-thumb {
      width: 25px;
      height: 25px;
      border-radius: 50%;
      background: #667eea;
      cursor: pointer;
      border: none;
    }

    .controls {
      display: grid;
      grid-template-columns: repeat(3, 1fr);
      gap: 10px;
      margin-top: 20px;
    }

    .btn {
      background: #667eea;
      color: white;
      border: none;
      border-radius: 10px;
      padding: 20px;
      font-size: 1.2em;
      cursor: pointer;
      transition: all 0.3s;
      user-select: none;
      -webkit-user-select: none;
      touch-action: manipulation;
    }

    .btn:active {
      background: #5568d3;
      transform: scale(0.95);
    }

    .btn:disabled {
      background: #ccc;
      cursor: not-allowed;
    }

    .btn-forward {
      grid-column: 2;
    }

    .btn-left {
      grid-column: 1;
      grid-row: 2;
    }

    .btn-stop {
      grid-column: 2;
      grid-row: 2;
      background: #e74c3c;
    }

    .btn-stop:active {
      background: #c0392b;
    }

    .btn-right {
      grid-column: 3;
      grid-row: 2;
    }

    .btn-backward {
      grid-column: 2;
      grid-row: 3;
    }

    .status {
      text-align: center;
      margin-top: 20px;
      padding: 10px;
      background: #f0f0f0;
      border-radius: 10px;
      color: #666;
    }

    .settings-btn {
      position: absolute;
      top: 15px;
      right: 15px;
      background: #888;
      color: white;
      border: none;
      border-radius: 50%;
      width: 40px;
      height: 40px;
      font-size: 1.5em;
      cursor: pointer;
      display: flex;
      align-items: center;
      justify-content: center;
      transition: all 0.3s;
    }

    .settings-btn:active {
      background: #666;
      transform: scale(0.95);
    }

    .control-toggle-btn {
      position: absolute;
      top: 15px;
      left: 15px;
      background: #667eea;
      color: white;
      border: none;
      border-radius: 50%;
      width: 40px;
      height: 40px;
      font-size: 1em;
      font-weight: bold;
      cursor: pointer;
      display: flex;
      align-items: center;
      justify-content: center;
      transition: all 0.3s;
    }

    .control-toggle-btn:active {
      background: #5568d3;
      transform: scale(0.95);
    }

    .joystick-container {
      display: none;
      position: relative;
      width: 200px;
      height: 200px;
      margin: 30px auto;
      background: #f0f0f0;
      border-radius: 50%;
      box-shadow: inset 0 0 20px rgba(0,0,0,0.1);
      touch-action: none;
      user-select: none;
      -webkit-user-select: none;
    }

    .joystick-container.active {
      display: block;
    }

    .joystick-knob {
      position: absolute;
      width: 80px;
      height: 80px;
      background: #667eea;
      border-radius: 50%;
      top: 50%;
      left: 50%;
      transform: translate(-50%, -50%);
      cursor: grab;
      box-shadow: 0 4px 10px rgba(0,0,0,0.3);
      transition: background 0.2s;
      touch-action: none;
      user-select: none;
      -webkit-user-select: none;
    }

    .joystick-knob:active {
      cursor: grabbing;
      background: #5568d3;
    }

    .controls.hide {
      display: none;
    }

    .modal {
      display: none;
      position: fixed;
      z-index: 1000;
      left: 0;
      top: 0;
      width: 100%;
      height: 100%;
      background-color: rgba(0,0,0,0.5);
      align-items: center;
      justify-content: center;
    }

    .modal.show {
      display: flex;
    }

    .modal-content {
      background: white;
      padding: 30px;
      border-radius: 20px;
      max-width: 400px;
      width: 90%;
      position: relative;
    }

    .close-btn {
      position: absolute;
      top: 10px;
      right: 15px;
      font-size: 2em;
      color: #888;
      cursor: pointer;
      border: none;
      background: none;
      line-height: 1;
    }

    .close-btn:hover {
      color: #333;
    }

    .trim-control {
      margin-top: 20px;
    }

    @media (max-width: 480px) {
      .container {
        padding: 20px;
      }

      h1 {
        font-size: 1.5em;
      }

      .btn {
        padding: 15px;
        font-size: 1em;
      }

      .settings-btn {
        width: 35px;
        height: 35px;
        font-size: 1.2em;
      }

      .control-toggle-btn {
        width: 35px;
        height: 35px;
        font-size: 1em;
      }
    }
  </style>
</head>
<body>
  <div class="container">
    <button class="control-toggle-btn" id="controlToggleBtn" title="Toggle Joystick">JS</button>
    <button class="settings-btn" id="settingsBtn">&#9881;</button>

    <h1>TankBot</h1>

    <div class="speed-control">
      <label class="speed-label">Speed Control</label>
      <div class="speed-value" id="speedDisplay">Medium</div>
      <input type="range" min="1" max="3" value="2" class="speed-slider" id="speedSlider">
    </div>

    <!-- Joystick Control -->
    <div class="joystick-container" id="joystickContainer">
      <div class="joystick-knob" id="joystickKnob"></div>
    </div>

    <!-- Button Controls -->
    <div class="controls" id="buttonControls">
      <button class="btn btn-forward" id="btnForward">^<br>Forward</button>
      <button class="btn btn-left" id="btnLeft">&lt;<br>Left</button>
      <button class="btn btn-stop" id="btnStop">X<br>Stop</button>
      <button class="btn btn-right" id="btnRight">&gt;<br>Right</button>
      <button class="btn btn-backward" id="btnBackward">v<br>Backward</button>
    </div>

    <div class="status" id="status">Ready</div>
  </div>

  <!-- Settings Modal -->
  <div class="modal" id="settingsModal">
    <div class="modal-content">
      <button class="close-btn" id="closeModal">&times;</button>
      <h2 style="margin-top: 0; color: #333;">Settings</h2>

      <div class="trim-control">
        <label class="speed-label">Steering Trim</label>
        <div class="speed-value" id="trimDisplay">Center</div>
        <input type="range" min="-20" max="20" value="0" class="speed-slider" id="trimSlider">
        <div style="font-size: 0.8em; color: #888; margin-top: 5px;">Left &larr; | &rarr; Right</div>
        <div style="font-size: 0.85em; color: #666; margin-top: 15px; line-height: 1.4;">
          Adjust this slider to compensate for uneven track tension. If your robot drifts left, move the slider right, and vice versa.
        </div>
      </div>
    </div>
  </div>

  <script>
    const speedSlider = document.getElementById('speedSlider');
    const speedDisplay = document.getElementById('speedDisplay');
    const trimSlider = document.getElementById('trimSlider');
    const trimDisplay = document.getElementById('trimDisplay');
    const status = document.getElementById('status');
    const settingsBtn = document.getElementById('settingsBtn');
    const settingsModal = document.getElementById('settingsModal');
    const closeModal = document.getElementById('closeModal');
    const controlToggleBtn = document.getElementById('controlToggleBtn');
    const joystickContainer = document.getElementById('joystickContainer');
    const joystickKnob = document.getElementById('joystickKnob');
    const buttonControls = document.getElementById('buttonControls');

    const speedNames = ['', 'Slow', 'Medium', 'Fast'];
    let joystickMode = false;
    let joystickActive = false;
    let joystickInterval = null;

    // Settings modal controls
    settingsBtn.addEventListener('click', function() {
      settingsModal.classList.add('show');
    });

    closeModal.addEventListener('click', function() {
      settingsModal.classList.remove('show');
    });

    // Close modal when clicking outside
    settingsModal.addEventListener('click', function(e) {
      if (e.target === settingsModal) {
        settingsModal.classList.remove('show');
      }
    });

    // Control mode toggle
    controlToggleBtn.addEventListener('click', function() {
      joystickMode = !joystickMode;
      if (joystickMode) {
        joystickContainer.classList.add('active');
        buttonControls.classList.add('hide');
      } else {
        joystickContainer.classList.remove('active');
        buttonControls.classList.remove('hide');
        sendCommand('move', 'stop');
      }
    });

    // Joystick control logic
    function handleJoystick(e) {
      e.preventDefault();
      const rect = joystickContainer.getBoundingClientRect();
      const centerX = rect.width / 2;
      const centerY = rect.height / 2;

      let clientX, clientY;
      if (e.type.includes('touch')) {
        clientX = e.touches[0].clientX - rect.left;
        clientY = e.touches[0].clientY - rect.top;
      } else {
        clientX = e.clientX - rect.left;
        clientY = e.clientY - rect.top;
      }

      let deltaX = clientX - centerX;
      let deltaY = clientY - centerY;

      // Constrain to circle
      const distance = Math.sqrt(deltaX * deltaX + deltaY * deltaY);
      const maxDistance = (rect.width / 2) - 40; // Keep knob inside

      if (distance > maxDistance) {
        const angle = Math.atan2(deltaY, deltaX);
        deltaX = Math.cos(angle) * maxDistance;
        deltaY = Math.sin(angle) * maxDistance;
      }

      // Update knob position
      joystickKnob.style.transform = `translate(calc(-50% + ${deltaX}px), calc(-50% + ${deltaY}px))`;

      // Calculate motor speeds based on position
      // deltaY: negative = forward, positive = backward
      // deltaX: negative = left, positive = right
      const forwardPower = -deltaY / maxDistance; // -1 to 1
      const turnPower = deltaX / maxDistance; // -1 to 1

      // Tank drive: mix forward and turn
      let leftMotor = forwardPower - turnPower;
      let rightMotor = forwardPower + turnPower;

      // Normalize if over 1
      const maxPower = Math.max(Math.abs(leftMotor), Math.abs(rightMotor));
      if (maxPower > 1) {
        leftMotor /= maxPower;
        rightMotor /= maxPower;
      }

      // Send control command
      sendJoystickCommand(leftMotor, rightMotor);
    }

    function sendJoystickCommand(left, right) {
      // Convert -1 to 1 range to motor direction and speed
      const leftDir = left >= 0 ? 'forward' : 'backward';
      const rightDir = right >= 0 ? 'forward' : 'backward';
      const leftSpeed = Math.abs(left);
      const rightSpeed = Math.abs(right);

      // Determine overall direction
      if (Math.abs(left) < 0.1 && Math.abs(right) < 0.1) {
        sendCommand('move', 'stop');
      } else {
        // Send a combined command with left and right motor values
        fetch(`/joystick?left=${left.toFixed(2)}&right=${right.toFixed(2)}`)
          .then(response => response.text())
          .then(data => {
            status.textContent = data;
          })
          .catch(error => {
            console.error('Joystick error:', error);
          });
      }
    }

    function resetJoystick() {
      joystickKnob.style.transform = 'translate(-50%, -50%)';
      sendCommand('move', 'stop');
      joystickActive = false;
    }

    // Joystick event listeners
    joystickKnob.addEventListener('mousedown', function() {
      joystickActive = true;
    });

    joystickKnob.addEventListener('touchstart', function() {
      joystickActive = true;
    });

    document.addEventListener('mousemove', function(e) {
      if (joystickActive && joystickMode) {
        handleJoystick(e);
      }
    });

    document.addEventListener('touchmove', function(e) {
      if (joystickActive && joystickMode) {
        handleJoystick(e);
      }
    });

    document.addEventListener('mouseup', function() {
      if (joystickActive) {
        resetJoystick();
      }
    });

    document.addEventListener('touchend', function() {
      if (joystickActive) {
        resetJoystick();
      }
    });

    // Update speed display
    speedSlider.addEventListener('input', function() {
      const speed = this.value;
      speedDisplay.textContent = speedNames[speed];
      sendCommand('speed', speed);
    });

    // Update trim display and send command
    trimSlider.addEventListener('input', function() {
      const trim = parseInt(this.value);
      if (trim === 0) {
        trimDisplay.textContent = 'Center';
      } else if (trim < 0) {
        trimDisplay.textContent = 'Left ' + Math.abs(trim);
      } else {
        trimDisplay.textContent = 'Right ' + trim;
      }
      sendCommand('trim', trim);
    });

    // Button event listeners
    document.getElementById('btnForward').addEventListener('mousedown', () => sendCommand('move', 'forward'));
    document.getElementById('btnForward').addEventListener('touchstart', (e) => { e.preventDefault(); sendCommand('move', 'forward'); });

    document.getElementById('btnBackward').addEventListener('mousedown', () => sendCommand('move', 'backward'));
    document.getElementById('btnBackward').addEventListener('touchstart', (e) => { e.preventDefault(); sendCommand('move', 'backward'); });

    document.getElementById('btnLeft').addEventListener('mousedown', () => sendCommand('move', 'left'));
    document.getElementById('btnLeft').addEventListener('touchstart', (e) => { e.preventDefault(); sendCommand('move', 'left'); });

    document.getElementById('btnRight').addEventListener('mousedown', () => sendCommand('move', 'right'));
    document.getElementById('btnRight').addEventListener('touchstart', (e) => { e.preventDefault(); sendCommand('move', 'right'); });

    document.getElementById('btnStop').addEventListener('mousedown', () => sendCommand('move', 'stop'));
    document.getElementById('btnStop').addEventListener('touchstart', (e) => { e.preventDefault(); sendCommand('move', 'stop'); });

    // Stop on button release
    document.addEventListener('mouseup', () => sendCommand('move', 'stop'));
    document.addEventListener('touchend', () => sendCommand('move', 'stop'));

    function sendCommand(type, value) {
      fetch(`/${type}?value=${value}`)
        .then(response => response.text())
        .then(data => {
          status.textContent = data;
        })
        .catch(error => {
          status.textContent = 'Error: ' + error;
        });
    }

    // Load saved trim value on page load
    fetch('/getTrim')
      .then(response => response.text())
      .then(trim => {
        const trimValue = parseInt(trim);
        trimSlider.value = trimValue;
        if (trimValue === 0) {
          trimDisplay.textContent = 'Center';
        } else if (trimValue < 0) {
          trimDisplay.textContent = 'Left ' + Math.abs(trimValue);
        } else {
          trimDisplay.textContent = 'Right ' + trimValue;
        }
      })
      .catch(error => {
        console.log('Could not load trim value');
      });
  </script>
</body>
</html>
)=====";

void setupMotors() {
  // Set pin modes
  pinMode(IN1, OUTPUT);
  pinMode(IN2, OUTPUT);
  pinMode(IN3, OUTPUT);
  pinMode(IN4, OUTPUT);

  // Configure PWM channels
  ledcSetup(PWM_CHANNEL_A, PWM_FREQ, PWM_RESOLUTION);
  ledcSetup(PWM_CHANNEL_B, PWM_FREQ, PWM_RESOLUTION);

  // Attach PWM channels to pins
  ledcAttachPin(ENA, PWM_CHANNEL_A);
  ledcAttachPin(ENB, PWM_CHANNEL_B);

  // Start with motors stopped
  stopMotors();
}

void stopMotors() {
  digitalWrite(IN1, LOW);
  digitalWrite(IN2, LOW);
  digitalWrite(IN3, LOW);
  digitalWrite(IN4, LOW);
  ledcWrite(PWM_CHANNEL_A, 0);
  ledcWrite(PWM_CHANNEL_B, 0);
}

void moveForward() {
  // What was "turnRight" - both motors spin to move forward
  // Apply trim: negative trim = slow left motor, positive trim = slow right motor
  int leftSpeed = currentSpeed;
  int rightSpeed = currentSpeed;

  if (motorTrim < 0) {
    leftSpeed = currentSpeed + motorTrim;  // Reduce left motor speed
  } else if (motorTrim > 0) {
    rightSpeed = currentSpeed - motorTrim; // Reduce right motor speed
  }

  // Ensure speeds stay in valid range
  leftSpeed = constrain(leftSpeed, 0, 255);
  rightSpeed = constrain(rightSpeed, 0, 255);

  digitalWrite(IN1, HIGH);
  digitalWrite(IN2, LOW);
  digitalWrite(IN3, LOW);
  digitalWrite(IN4, HIGH);
  ledcWrite(PWM_CHANNEL_A, leftSpeed);
  ledcWrite(PWM_CHANNEL_B, rightSpeed);
}

void moveBackward() {
  // What was "turnLeft" - both motors reverse
  // Apply trim: negative trim = slow left motor, positive trim = slow right motor
  int leftSpeed = currentSpeed;
  int rightSpeed = currentSpeed;

  if (motorTrim < 0) {
    leftSpeed = currentSpeed + motorTrim;  // Reduce left motor speed
  } else if (motorTrim > 0) {
    rightSpeed = currentSpeed - motorTrim; // Reduce right motor speed
  }

  // Ensure speeds stay in valid range
  leftSpeed = constrain(leftSpeed, 0, 255);
  rightSpeed = constrain(rightSpeed, 0, 255);

  digitalWrite(IN1, LOW);
  digitalWrite(IN2, HIGH);
  digitalWrite(IN3, HIGH);
  digitalWrite(IN4, LOW);
  ledcWrite(PWM_CHANNEL_A, leftSpeed);
  ledcWrite(PWM_CHANNEL_B, rightSpeed);
}

void turnLeft() {
  // What was "moveForward" - spin left
  digitalWrite(IN1, HIGH);
  digitalWrite(IN2, LOW);
  digitalWrite(IN3, HIGH);
  digitalWrite(IN4, LOW);
  ledcWrite(PWM_CHANNEL_A, currentSpeed);
  ledcWrite(PWM_CHANNEL_B, currentSpeed);
}

void turnRight() {
  // What was "moveBackward" - spin right
  digitalWrite(IN1, LOW);
  digitalWrite(IN2, HIGH);
  digitalWrite(IN3, LOW);
  digitalWrite(IN4, HIGH);
  ledcWrite(PWM_CHANNEL_A, currentSpeed);
  ledcWrite(PWM_CHANNEL_B, currentSpeed);
}

void handleRoot() {
  server.send(200, "text/html", MAIN_page);
}

// Handle captive portal detection requests
void handleCaptivePortal() {
  server.send(200, "text/html", MAIN_page);
}

void handleMove() {
  if (server.hasArg("value")) {
    String direction = server.arg("value");

    if (direction == "forward") {
      moveForward();
      server.send(200, "text/plain", "Moving Forward");
    }
    else if (direction == "backward") {
      moveBackward();
      server.send(200, "text/plain", "Moving Backward");
    }
    else if (direction == "left") {
      turnLeft();
      server.send(200, "text/plain", "Turning Left");
    }
    else if (direction == "right") {
      turnRight();
      server.send(200, "text/plain", "Turning Right");
    }
    else if (direction == "stop") {
      stopMotors();
      server.send(200, "text/plain", "Stopped");
    }
    else {
      server.send(400, "text/plain", "Invalid direction");
    }
  } else {
    server.send(400, "text/plain", "Missing direction parameter");
  }
}
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
void loop() {
  dnsServer.processNextRequest();
  server.handleClient();
}

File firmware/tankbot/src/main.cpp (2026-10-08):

// TankBot firmware v3: generic sensor table + directional reflexes.
//
// The robot's hardware description (name, drive type, motor/lidar pins, and a list of sensors with
// slot, position, yaw, tilt, role and thresholds) lives in flash as JSON and is edited from the
// brain's Bot page (or, with no brain, from /setup). Drivers are created from the table, so any
// number of bumpers / rangers facing any direction are just entries.
//
// UDP: 5601 lidar (docs/protocol.md), 5602 motion, 5603 sensors ("TSSUB" -> "TCAP1"+hardware JSON
// once, then "TSN1"+readings at 20 Hz). HTTP: /api/hardware (GET, POST JSON -> save + restart),
// /api/sensors, /tof/calibrate?id=..., /setup (fallback page).

#include <Arduino.h>
#include <WiFi.h>
#include <WiFiUdp.h>
#include <WebServer.h>
#include <ESPmDNS.h>
#include <DNSServer.h>
#include <Preferences.h>
#include <ArduinoOTA.h>
#include <ArduinoJson.h>
#include <LittleFS.h>
#include "mbedtls/base64.h"
#include <math.h>
#include "esp_timer.h"
#include "secrets.h"
#include "web_ui.h"

static const char *FW_VERSION = "3.1";

// ================= hardware description =================
enum SType { ST_BUMPER, ST_TOF, ST_ULTRASONIC, ST_IMU, ST_LIDAR, ST_CAMERA, ST_OTHER };
enum SRole { ROLE_OBSTACLE, ROLE_CLIFF, ROLE_BUMP, ROLE_ORIENTATION, ROLE_MAPPING, ROLE_NONE };
enum Dir { DIR_FRONT = 0, DIR_LEFT = 1, DIR_BACK = 2, DIR_RIGHT = 3 };

struct Sensor {
  char id[16] = "";
  char name[24] = "";
  SType type = ST_OTHER;
  char slot[10] = "";        // BUMP1 BUMP2 TOF US1 US2 I2C LIDAR CUSTOM NONE
  int pinA = -1, pinB = -1;  // resolved from slot (or custom): bumper pin / trig,echo / rx,tx
  SRole role = ROLE_NONE;
  bool enabled = true;
  char err[56] = "";         // wiring problem found at startup: the sensor is not started
  float yawDeg = 0;          // 0 front, +left
  bool floorTilt = false;    // pointed at the floor (cliff sensing)
  int stopMm = 150;          // obstacle role: block when closer
  int floorMm = 0;           // cliff role: calibrated floor reading (0 = not calibrated)
  int backoffMs = 150;       // bump role: reverse this long after a hit (0 = just stop)
  float left = 0, front = 0, height = 0, width = 0; // placement for the brain (mm)
  // live
  int value = -1;            // mm, or 1/0 for bumpers
  bool ok = false;
  uint32_t lastMs = 0;
  // ultrasonic timing
  volatile uint32_t echoStart = 0, echoUs = 0; volatile bool echoDone = false; uint32_t lastTrigMs = 0;
};

static const int MAX_SENSORS = 12;
Sensor sensors[MAX_SENSORS];
int nSensors = 0;

struct Hardware {
  char name[24] = "TankBot";
  char drive[12] = "tank";
  int in1 = 16, in2 = 17, in3 = 18, in4 = 19, ena = 25, enb = 26;
  int lidarRx = 4, lidarTx = 27;
  bool lidar = true;
  int speed = 255, trim = 0;
} hw;

const char *typeName(SType t) {
  switch (t) { case ST_BUMPER: return "bumper"; case ST_TOF: return "tof"; case ST_ULTRASONIC: return "ultrasonic";
    case ST_IMU: return "imu"; case ST_LIDAR: return "lidar"; case ST_CAMERA: return "camera"; default: return "other"; }
}
SType typeFrom(const char *s) {
  if (!strcmp(s, "bumper")) return ST_BUMPER; if (!strcmp(s, "tof")) return ST_TOF; if (!strcmp(s, "ultrasonic")) return ST_ULTRASONIC;
  if (!strcmp(s, "imu")) return ST_IMU; if (!strcmp(s, "lidar")) return ST_LIDAR; if (!strcmp(s, "camera")) return ST_CAMERA; return ST_OTHER;
}
const char *roleName(SRole r) {
  switch (r) { case ROLE_OBSTACLE: return "obstacle"; case ROLE_CLIFF: return "cliff"; case ROLE_BUMP: return "bump";
    case ROLE_ORIENTATION: return "orientation"; case ROLE_MAPPING: return "mapping"; default: return "none"; }
}
SRole roleFrom(const char *s) {
  if (!strcmp(s, "obstacle")) return ROLE_OBSTACLE; if (!strcmp(s, "cliff")) return ROLE_CLIFF; if (!strcmp(s, "bump")) return ROLE_BUMP;
  if (!strcmp(s, "orientation")) return ROLE_ORIENTATION; if (!strcmp(s, "mapping")) return ROLE_MAPPING; return ROLE_NONE;
}
Dir dirOf(float yawDeg) {
  float y = fmodf(yawDeg + 540.0f, 360.0f) - 180.0f;
  if (fabsf(y) <= 45) return DIR_FRONT;
  if (fabsf(y) >= 135) return DIR_BACK;
  return y > 0 ? DIR_LEFT : DIR_RIGHT;
}
const char *dirName(Dir d) { return d == DIR_FRONT ? "front" : d == DIR_LEFT ? "left" : d == DIR_BACK ? "back" : "right"; }

/// Standard-board slots -> pins. docs/wiring.md
void resolveSlot(Sensor &s) {
  if (!strcmp(s.slot, "BUMP1")) { s.pinA = 13; s.pinB = -1; }
  else if (!strcmp(s.slot, "BUMP2")) { s.pinA = 23; s.pinB = -1; }
  else if (!strcmp(s.slot, "TOF")) { s.pinA = 32; s.pinB = 33; }      // ToF T -> 32 (rx), R <- 33 (tx)
  else if (!strcmp(s.slot, "US1")) { s.pinA = 14; s.pinB = 34; }      // trig, echo
  else if (!strcmp(s.slot, "US2")) { s.pinA = 2; s.pinB = 35; }
  else if (!strcmp(s.slot, "I2C")) { s.pinA = 21; s.pinB = 22; }
  else if (!strcmp(s.slot, "LIDAR")) { s.pinA = hw.lidarRx; s.pinB = hw.lidarTx; }
  // CUSTOM keeps the pins given; NONE (phone camera etc.) has no pins
}

Preferences prefs;

String hardwareJson(bool withLive);

void defaultSensors() {
  nSensors = 0;
  Sensor &l = sensors[nSensors++];
  strcpy(l.id, "lidar"); strcpy(l.name, "RPLidar"); l.type = ST_LIDAR; strcpy(l.slot, "LIDAR"); l.role = ROLE_MAPPING;
  l.left = 92; l.front = 40; l.height = 200;
  resolveSlot(l);
}
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

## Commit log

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2026-09-24 Add combined TankBot firmware (motion+watchdog, lidar, web UI with hold-to-drive), rename host to tankbot.local, app fixes
    [main.cpp]
2026-09-24 App: joystick driving with watchdog-friendly 20 Hz commands, speed limit, obstacle stop, motion status
2026-09-27 Brain control server: web remote with joystick/map/radar, remote watchdog, robot mode, keep-awake, lidar offset
2026-09-27 Motion: minimum PWM mapping + kick-start so the tracks actually move on the floor
2026-09-27 Revert "Motion: minimum PWM mapping + kick-start so the tracks actually move on the floor"
    This reverts commit 9e80fb844a9e9c7e8132b0bc0d8279cf6ca364e2.
    [main.cpp]
2026-09-27 Mount detection: map only once the phone is settled in the cradle, lidar-checked disturbance guard, New map here
2026-09-27 Remote settings panel: steering trim (saved on robot) and obstacle stop distance
2026-09-27 Capability report, lidar scan matching (likelihood field), lidar-only tracking fallback, lidar relocalisation, auto-load last map, tests
2026-09-27 Nav: 200x200 footprint, smoothed/ramped control with hysteresis, replan-instead-of-stop, tighter waypoints; reloc from last pose/home first, finer global search; Find me / I am at home buttons
2026-09-27 Phase 1: roadmap, bot profile (format, storage, derived lidar offset and footprint), Bot tab editor with top and side views
2026-09-27 Nav: profile power levels (min-to-move, cruise); straight-or-turn control with no sub-threshold commands; Bot page power fields
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2026-09-27 Firmware v2: flash-stored config + /setup page, sensor modules (bumpers, TOFSense UART, ultrasonic), on-board reflexes, capability announce + sensor feed (UDP 5603), Wi-Fi fallback recovery; standard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
2026-09-27 Brain reads robot capabilities + sensor feed; Robot section in Settings; pass distance + typed stop/pass fields; decisive full-power turns with min burst; full PWM range; nav honours ESP32 reflexes; 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
2026-09-27 Nav turning: direction re-checked each tick, pulsed final approach (fixes spin); profile pre-fill from robot capabilities; bumper hits become map obstacles; ultrasonic as live obstacle
2026-09-27 Phase 3: app roles (mounted brain / brain in hand / controller), in-app controller via WebView, architecture note
2026-09-27 Per-robot storage: profiles and maps under robots/<name>, one-time migration, automatic switch when a different robot announces itself
2026-09-27 Phase 4: depth-camera obstacle layer (ARKit scene depth -> low obstacles and drop-offs) feeding guardian, planner and map view; tests
2026-09-28 Depth camera stop distance + obstacle height settings; save position on role change; reject 180-degree-ambiguous quick relocalisation; on-screen confirmations
2026-10-01 Profile v2: platform height, platform-relative sensor heights, bumper bars with width and protrusion; Bot page updated; old profiles converted
2026-10-04 Firmware v3: generic sensor table (slots, pose, role, thresholds) in flash, directional reflexes, /api/hardware read/write, v2 migration
2026-10-04 Bot page is the single editor: robot sensor table (slot, role, facing, floor tilt, thresholds, placement) read from and written to the ESP32; live readings; slot checks; any number of rangers/bumpers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
2026-10-04 Robot HTTP: send body length (ESP32 cannot read chunked bodies); retry hardware sync every 15 s
2026-10-04 Bumper back-off: per-bumper duration (default 150 ms, 0 = stop), gentler power; ranger readings drawn on the map
2026-10-04 Sensor log: GPS + compass + tracked pose recorder (Settings > Sensor log) for evaluating phone sensors
2026-10-04 Controller redesign: page moved to assets/controller.html; consistent shell with status pills; pan/zoom/pinch/follow map with legend and scale; status tray + toasts; drive panel. Fixes: glossy-floor 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
2026-10-04 Set position: press where the robot is and drag its heading; lidar fine-tunes within 50 cm / 25 deg
2026-10-04 Trip recorder: every Go To logs each driving step (decision + reason, guard, re-plans, robot motor state, watchdog, event-loop lag); tools/analyze_nav.py
2026-10-04 Fix Go To stutter: manual-drive re-apply on every lidar scan was commanding stop during autonomous driving; steer gently while driving within the min-power margin
2026-10-05 Go To: turn only when >30 deg off, one direction per turn, stop at 12 deg or overshoot, settle 350 ms; steering handles the rest; re-plan on route obstacles only after 3 consecutive sightings, routin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
2026-10-06 Landscape mounting: Bot page phone mounting choice, robot mode locks to the mounted orientation, responsive two-column robot screen in landscape
2026-10-07 Mapping modes: Explore / Maintain (default) / Off; tracking always on; Maintain extends into unmapped ground and commits changes only after 3 passes over 10+ min; Go To caps Explore to Maintain; bump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
2026-10-07 Autonomous exploration: frontier search (nearest opening, skips unreachable), maps while exploring, returns home; cliff-sensor warning with per-map no-drops confirmation; stops on Stop, manual contro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
2026-10-07 Exploration: button only in Explore mapping mode; no-cliff-sensor acknowledgment (user supervises) asked every start, no per-map no-drops flag; switching mapping away from Explore stops exploring
2026-10-07 Exploration frontiers rebuilt (frontier.dart + tests): gaps under 60 cm count as closed wall, openings must lead to real unexplored space and be reachable by the robot body, own room first (doorways 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
2026-10-07 Navigation recovery: blocked ahead for >1.2 s -> temporary mark on the obstacle, back up 25 cm if the rear is clear (reflex, lidar strip, map), settle, re-plan; gives up on the goal after 4 tries or 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
2026-10-07 Drift recovery: widen the lidar match window after repeated misses, wide Set-position-style search every 1.5 s when still lost, snap to the lidar when it is confident and the camera is >10 cm off
2026-10-07 No teleporting while driving itself: relocalization only searches near where it was (whole map only when the user asks); big lidar corrections only when most of the scan is on known map; exploring pa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
2026-10-07 Stall detection: driven but not moving for ~2 s counts as a bump - autonomous driving marks the spot and backs up to go around; manual driving marks it and warns
2026-10-07 Tracking: fix camera-to-lidar switch starting from a stale pose (5 m jumps); distrust a camera that reports motion while motors are idle (30 s lidar-only); Settings choice auto / lidar only
2026-10-07 Camera glitch filter: impossible ARKit pose leaps between frames are smoothed over (pose stream stays continuous); position events log (relocalizations, tracking switches, camera jumps/drift, snaps, 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
2026-10-07 Fix glitch filter treating real 250 deg/s spins as glitches; skip lidar matching on scans smeared by fast spins (>60 deg/s); turn on the spot in pulses, never a continuous full-power spin
2026-10-07 Docs catch-up for v0.3: roadmap, architecture, protocol (sensor feed, brain announce, HTTP, controller WebSocket), bot profile v2, new user guide, diagnostics guide, changelog, tools README; tools/br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
2026-10-07 Fix flickering Robot not responding card: measure robot silence from the latest scan / sensor packet, not from the 4 s link check
2026-10-07 Defaults that drive well: stop 100 mm, pass 50 mm, depth stop 100 mm / height 40 mm, TankBot platform height 66 mm
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2026-10-07 Bench a broken camera: 3+ impossible camera jumps within 5 s switch to lidar-only tracking for a minute (lens covered, smudged or too dark)
2026-10-07 Lidar-only tracking uses the phone rotation between scans as the heading hint (fast turns no longer lose the heading); Set position searches every heading around the pressed spot when the dragged dir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
2026-10-07 Lidar + gyro tracking: raw CoreMotion gyro yaw (independent of the camera) as the turning hint, with automatic direction check; keep moving at recent speed through missed scans instead of freezing; A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
2026-10-07 README media and hardware: demo GIF at the top, photo gallery in Build one, driving GIF in Mapping and driving (photos stripped of all metadata); Printables link for the 3D-printed parts; backup copi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
    [TankBot Base.f3d, TankBot Base.stl, TankBot Battery Clamp.f3d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]
2026-10-07 README parts list (electronics, sensors, brain, M3x6 screws, printed spacers, wiring); Spacer 6x3x3 added to the model files with how it is used
    [TankBot Spacer 6x3x3.stl]
2026-10-07 Model files as the backup zip (hardware/tankbot-modelfiles.zip, includes the spacer) instead of loose files; Printables is the place to get the parts
    [TankBot Base.f3d, TankBot Base.stl, TankBot Battery Clamp.f3d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]
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2026-10-08 Wiring: Bot page Sensors | Wiring view (pin map of the expansion board, pin budget, default or custom pins for the motor driver, lidar and every sensor, validation, live readings, motor tests, swap/r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
    [main.cpp]
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
